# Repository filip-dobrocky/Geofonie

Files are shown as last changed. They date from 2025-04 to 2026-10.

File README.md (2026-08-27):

# Geofonie
A networked sound art installation born out of [Trychtyr](https://svitava.org/project/trychtyr/) project of [SVITAVA transmedia art lab](https://svitava.org/).

This repository contains all of the software and also the hardware documentation.

The ESP32 firmware is in the `PlatformIO` directory, the `Daisy` directory contains Gen patches for [Oopsy](github.com/electro-smith/oopsy/), current: `Granular/geofonie_gen_simpler2.maxpat`.

# Dependencies
- [OSC Control](https://git.iem.at/uC/OSC_control)
- [MIDI Library](https://docs.arduino.cc/libraries/midi-library/)
- [ESP-FlexyStepper](https://docs.arduino.cc/libraries/esp-flexystepper/)
- [ESP32Servo](https://docs.arduino.cc/libraries/esp32servo/)
- [Pololu VL53L4CD](https://github.com/pololu/vl53l4cd-arduino)

# Roto MIDI messages:
    CC1: sensor value
    CC2: servo min angle / (sample pos) loop start pos
    CC3: servo max angle / (sample pos) loop end pos
    CC4: rotation speed  / (sample pos) loop speed
    CC5..12: misc1..8

# OSC messages:
    [obj_id]: 0, 1, 2, 3, 4
    [value] : 0..1

## Roto objects

### Rotation
#### Speed:
`/toRoto/rotation/speed [obj_id] [value]`  
#### Direction:
`/toRoto/rotation/direction [obj_id] [value]`  

### Servo
#### Center position:  
`/toRoto/servo/center [obj_id] [value]`  
#### Angle range (0 = no movement):  
`/toRoto/servo/angle [obj_id] [value]`  
#### Movement mode:
    0 = STATIC
    1 = ALTERNATING
    2 = LINEAR
`/toRoto/servo/mode [obj_id] [value]`  
#### Movement direction (0 / 1):  
`/toRoto/servo/direction [obj_id] [value]`  
#### Servo calibration (0 / 1):
Stop automatic movement and set angle based on `center` message  
`/toRoto/servo/calibrate [obj_id] [value]`  

### Sensor calibration
#### Lower limit:
`/toRoto/calibration/minDist [obj_id] [value]`  
#### Upper limit:
`/toRoto/calibration/maxDist [obj_id] [value]`  
#### Auto-calibration (0 / 1):
Scans the object once: the servo is held still for a full rotation at each angle, then
the distance window (`minDist`/`maxDist`) and the servo tilt band (`center`/`angle`) are
derived from what was measured. Takes about a minute. Runs on every startup, so the values
are never stored -- the object has usually moved by the next power-up anyway.  
`/toRoto/calibration/auto [obj_id] [value]`  
#### Measured calibration:
Sent from object to all devices when a scan finishes  
`/fromRoto/calibration [obj_id] [minDist] [maxDist] [center_angle] [angle_dif]`  

#### Value read from sensor (0..1):
Sent from object to all devices  
`/fromRoto/reading [obj_id] [value]`  

### Misc parameters:
Sent to Daisy Seed as MIDI CC 5-12 to be used as sound synthesis parameters  
`/toRoto/misc/[1-8] [obj_id] [value]`   

## Acid objects

Generic parameters sent to Daisy Seed as MIDI CC 1-10  
`/toAcid/param[1-10] [obj_id] [value]`  

## Global
### Rotation speed
`/toRoto/global/rotation/speed [value]`
### Rotation direction
`/toRoto/global/rotation/direction [value]`
### Roto misc
`/toRoto/global/misc/[1-8] [value]` 
### Sensor calibration
`/toRoto/global/calibration/minDist [value]`, `/toRoto/global/calibration/maxDist [value]`, `/toRoto/global/calibration/auto [value]`
### Acid params
`/toAcid/global/param[1-10] [value]` 

#### Object alive, with firmware version:
`/fromRoto/ping [obj_id] [fw_version]`, `/fromAcid/ping [obj_id] [fw_version]`

# Network config

Network parameters are defined in `NetworkConfig.h`

SSID: `TrychtyrLOM`
Password: `LomLomLom`

Port for sending to mesh objects: `54345`
Port for listening to messages from mesh: `54355`

There is no infrastructure access point. Every object runs painlessMesh in
AP_STA and advertises `TrychtyrLOM` as its own softAP, so **join any object's
AP** and send to its gateway address (`10.x.y.1`). That object relays every
`/to...` message it receives across the mesh, and re-emits telemetry it hears
from the mesh to its own AP, so it does not matter which one you attach to.
Roto and Acid share one mesh; Roto object 0 is the mesh root anchor.

# Firmware

Object ids live in NVS, not in the binary, so one image serves every object.

1. **Provision** each board once over USB with its own env: `xiao_dev_0` ...
   `xiao_dev_4` (in `ESPRoto/` or `ESPAcid/`). This writes the id and nothing
   else depends on it afterwards.
2. **Update** over the mesh: join any object's AP and run
   `python PlatformIO/tools/ota_update.py --project roto --watch`
   (`--project acid` for the Acid objects; the two roles cannot flash each
   other, so run it once per project). It builds `xiao_deploy`, uploads to the
   object's `/fw` endpoint, and that object distributes to the mesh and
   self-flashes last. `http://10.x.y.1/` serves the same thing as a form.

A crash-looping image can only be recovered over USB, so bench one board with
`xiao_ota` before distributing.

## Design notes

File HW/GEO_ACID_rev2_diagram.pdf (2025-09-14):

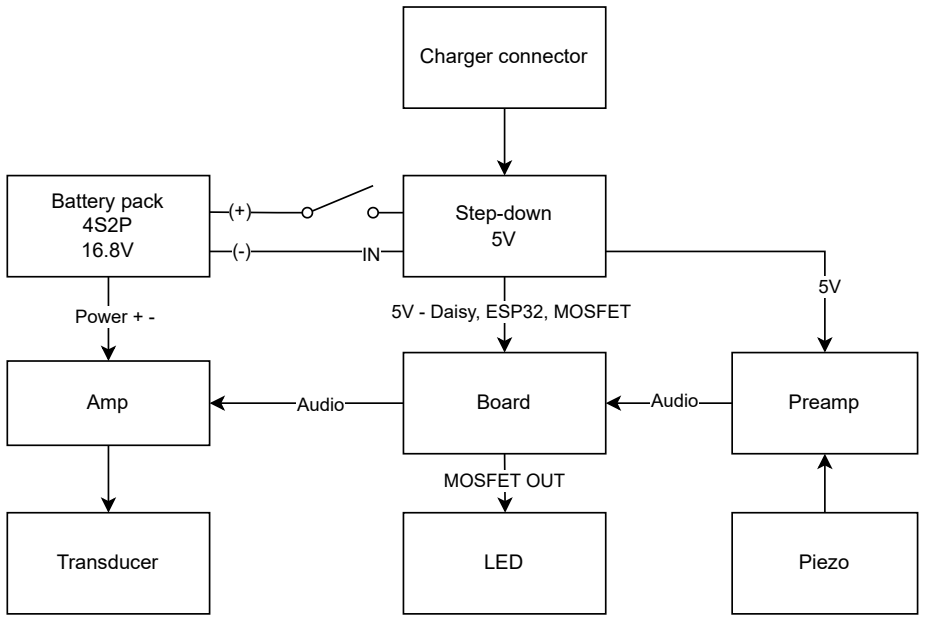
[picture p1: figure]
Power + -; Battery pack 4S2P 16.8V; 5V - Daisy, ESP32, MOSFET; Step-down; Amp; Transducer; Audio; MOSFET OUT; Board; Piezo; Preamp; Charger connector; LED

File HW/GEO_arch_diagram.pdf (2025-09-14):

COMMUNICATION + LOGIC | AUDIO

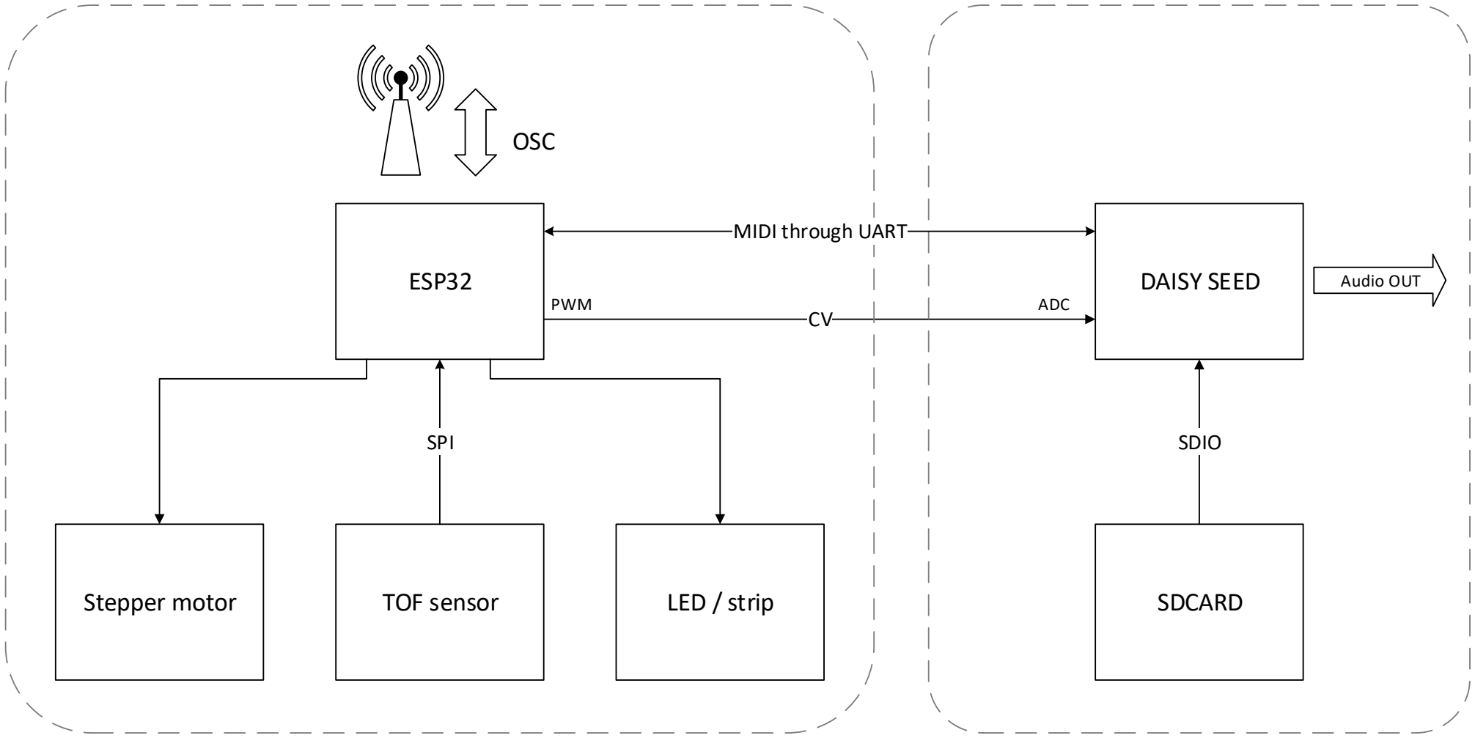
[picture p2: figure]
ESP32; OSC; Stepper motor; TOF sensor; LED / strip; DAISY SEED; SDCARD; SPI; SDIO; Audio OUT; PWM; ADC; MIDI through UART

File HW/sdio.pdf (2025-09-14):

D3 | D2 | D1 | D0 | CMD | CLK
3V | GND | CLK | D0 | CMD | D3 | D1 | D2

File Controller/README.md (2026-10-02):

# geo_controller

A new Flutter project.

## Getting Started

This project is a starting point for a Flutter application.

A few resources to get you started if this is your first Flutter project:

- [Learn Flutter](https://docs.flutter.dev/get-started/learn-flutter)
- [Write your first Flutter app](https://docs.flutter.dev/get-started/codelab)
- [Flutter learning resources](https://docs.flutter.dev/reference/learning-resources)

For help getting started with Flutter development, view the
[online documentation](https://docs.flutter.dev/), which offers tutorials,
samples, guidance on mobile development, and a full API reference.

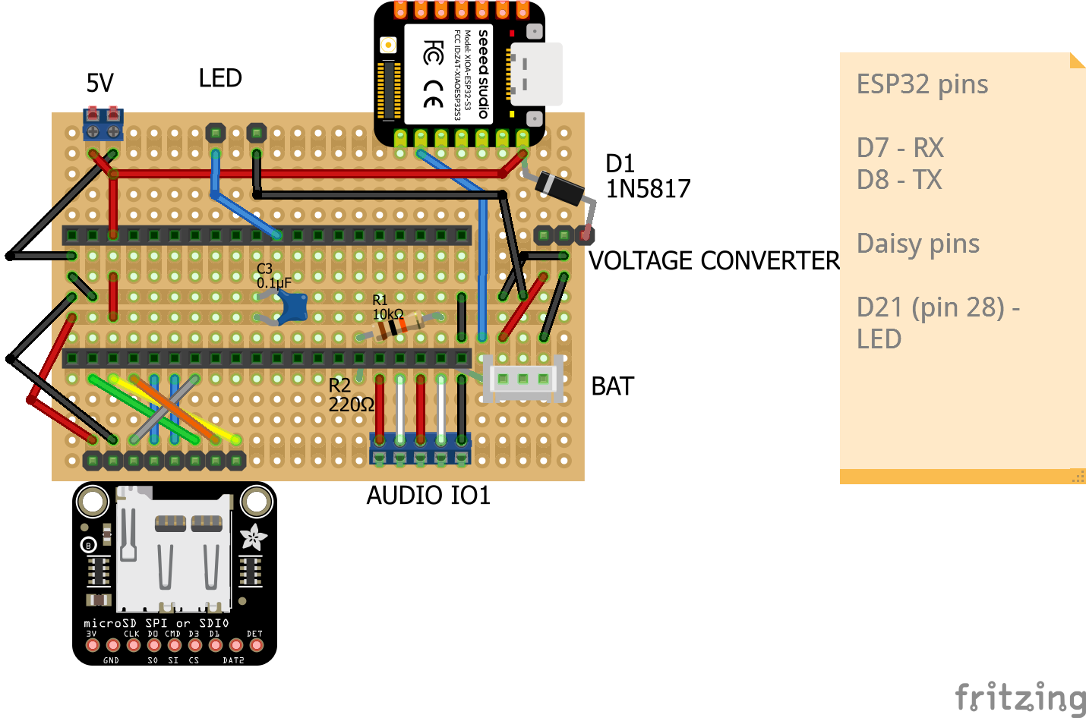
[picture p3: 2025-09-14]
HW/pcb_acid_rev1.png

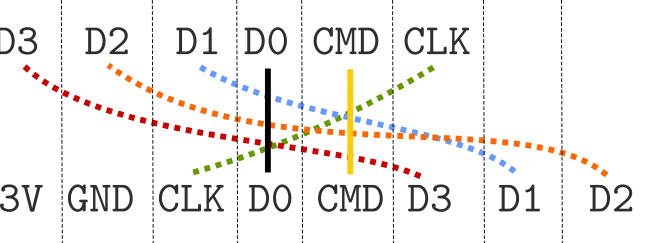
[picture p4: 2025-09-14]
HW/sdio.png

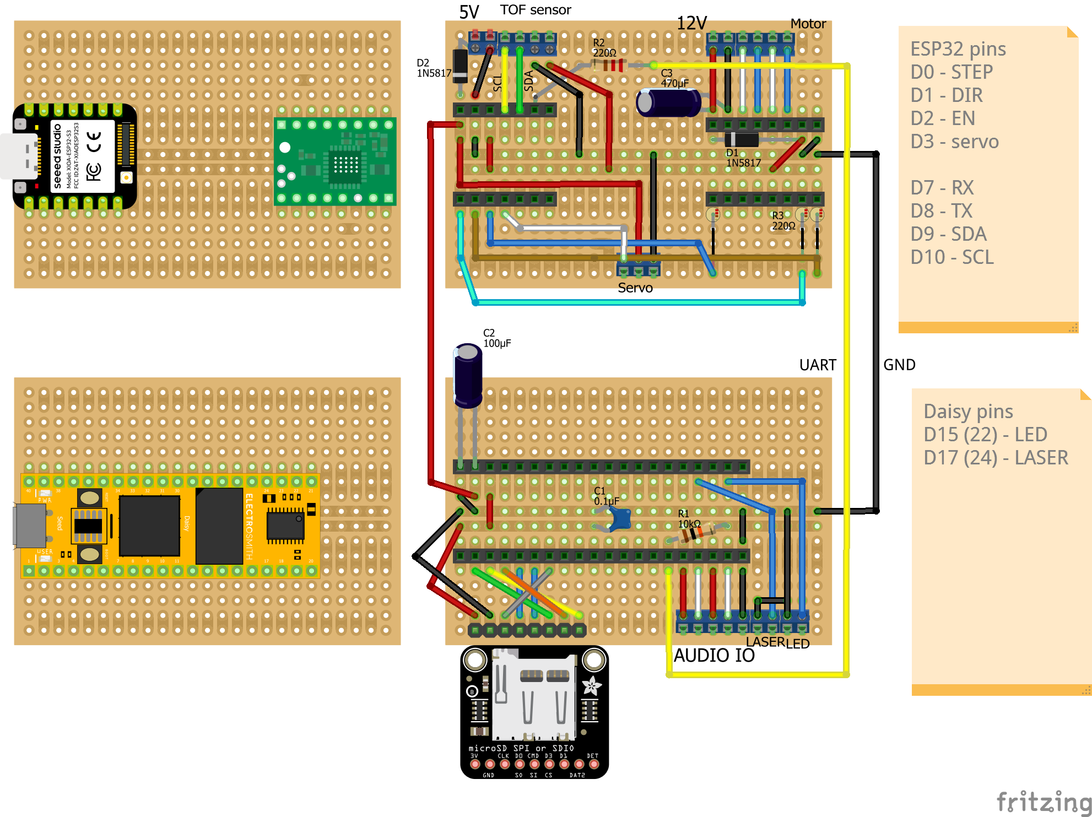
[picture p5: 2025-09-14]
HW/pcb_roto.png

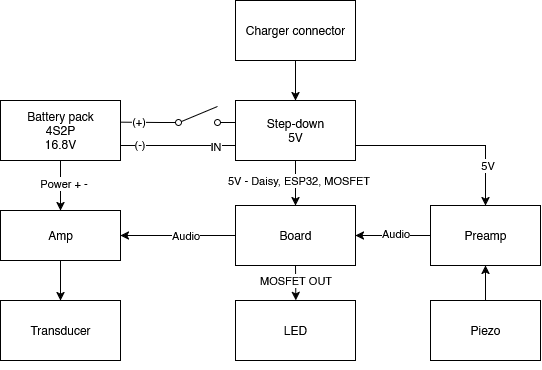
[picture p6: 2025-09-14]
HW/GEO_ACID_rev2_diagram.png

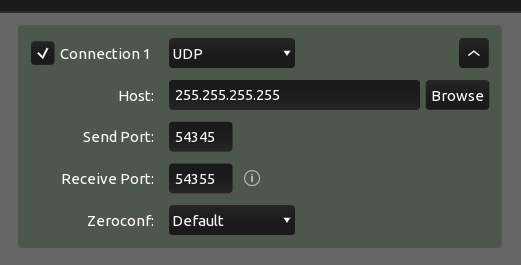
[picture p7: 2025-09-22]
TouchOSC/udp_config.png

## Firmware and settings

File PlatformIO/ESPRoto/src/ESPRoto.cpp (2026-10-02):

/*
 * ESPRoto.cpp
 * Part of Geofonie project
 * Copyright (C) 2024 Filip Dobrocky, Trychtyr collective
 *
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
 * You should have received a copy of the GNU General Public License
 * along with this program.  If not, see <https://www.gnu.org/licenses/>.
 */

#include <Arduino.h>
#include <MIDI.h>
#include <Wire.h>
#include <VL53L4CD.h>
#include <ESP_FlexyStepper.h>
#include <ESP32Servo.h>

// GeoNode.h (painlessMesh) must pull in TaskScheduler: it sets _TASK_STD_FUNCTION
// first, and including TaskScheduler.h ahead of it locks in a Task without
// std::function callbacks, which mesh.addTask() then fails to construct.
#include "GeoNode.h"
#include "GeoIdentity.h"
#include "GeoOta.h"
#include "GEOUtils.h"
#include "Smoothing.h"
#include "Sequencer.h"

// Constants
const char* TAG = "geo_roto";

#define FW_VERSION 2

// Object id at runtime: read from NVS by the generic OTA image, seeded over USB
// by the per-node provisioning envs (-DOBJ_ID=n). -1 means unprovisioned.
int g_obj_id = -1;

#ifndef BAD_DRIVER
#define BAD_DRIVER 0
#endif

#ifdef BOARD_XIAO
#define MS1_PIN D4
#define MS2_PIN D5
#define MS3_PIN D6

#define RX_PIN D7
#define TX_PIN D8

#define I2C_SDA D9
#define I2C_SCL D10

#define STEP_PIN D0
#define DIR_PIN D1
#define EN_PIN D2

#define SERVO_PIN D3
#endif

#define MIN_ANGLE 40
#define MAX_ANGLE 99

#define MIN_DISTANCE 120
#define MAX_DISTANCE 400

#define STEPS_PER_ROTATION 13500
#define DEGREES_PER_ROTATION 10

// ---- Auto-calibration ----
// Runs once per boot. Default: the servo stays at center_angle while the stepper
// turns CAL_TURNS times, and only the distance band is set. -DFULL_CALIBRATION
// instead holds the servo for a full rotation at each angle across the range and
// also derives the servo band (center/angle) from where the object is.
// Upper bound, not a haste setting: a rotation takes STEPS_PER_ROTATION/CAL_SPEED
// seconds and samples every SENSOR_PERIOD, so faster thins the azimuthal scan
// (4000 -> 3.4 s -> ~140 samples/rotation -> one every 2.6 degrees).
#define CAL_SPEED 4000
#ifdef FULL_CALIBRATION
#define CAL_ANGLE_STEP 4
#define CAL_ANGLE_COUNT (((MAX_ANGLE - MIN_ANGLE) / CAL_ANGLE_STEP) + 1)
#define CAL_TURNS 1
#else
#define CAL_ANGLE_COUNT 1
#define CAL_TURNS 2
#endif
// Servo travel between two adjacent stops; also lets the stepper reach speed.
#define CAL_SETTLE_MS 200
// Below this span across a rotation an angle is the pedestal, not the object.
#define CAL_FLAT_SPAN_MM 8
// Widens the measured window on each edge by this share of its span, so the
// extremes don't sit exactly on 0 and 127.
#define CAL_PAD_PCT 10
// Below this share of in-range samples the sensor is pointing past the object.
#define CAL_MIN_VALID_PCT 50

#define MISC_PARAM_NUM 8

// Sensor telemetry period. Every reading is a mesh broadcast, so five objects at
// 500 ms is already ~10 messages/s on a shared bus -- raise before lowering.
#define READING_PERIOD 500

// Sensor integration window (10..200 ms). Longer = quieter, and cheaper than
// averaging it back out in software. Trade against NUM_READINGS in Smoothing.h.
#define SENSOR_TIMING_BUDGET 20
// Poll margin: keep it above the budget so sense() isn't polling I2C for nothing.
#define SENSOR_PERIOD (SENSOR_TIMING_BUDGET + 4)

#ifndef NO_SENSOR
#define NO_SENSOR 0
#endif


// ---- Enums ----
enum TransportMode {
  STATIC,
  LINEAR,
  ALTERNATING
};

// ---- Globals ----
const char *base_address = "/toRoto";
const char *broadcast_address = "/fromRoto";

GeoConfig geo_cfg{-1, false, base_address, broadcast_address, "roto"};
GeoNode node(geo_cfg);
GeoOta ota(node.mesh(), "roto");

// ---- Misc OSC params  ----
constexpr int NUM_MISC = MISC_PARAM_NUM;
constexpr const char* misc_param_names[NUM_MISC] = {
  "/misc/1", "/misc/2", "/misc/3", "/misc/4",
  "/misc/5", "/misc/6", "/misc/7", "/misc/8"
};
constexpr const char* misc_param_names_global[NUM_MISC] = {
  "/global/misc/1", "/global/misc/2", "/global/misc/3", "/global/misc/4",
  "/global/misc/5", "/global/misc/6", "/global/misc/7", "/global/misc/8"
};
OSC_receive_msg rcv_misc[NUM_MISC] = {
  OSC_receive_msg(misc_param_names[0]),
  OSC_receive_msg(misc_param_names[1]),
  OSC_receive_msg(misc_param_names[2]),
  OSC_receive_msg(misc_param_names[3]),
  OSC_receive_msg(misc_param_names[4]),
  OSC_receive_msg(misc_param_names[5]),
  OSC_receive_msg(misc_param_names[6]),
  OSC_receive_msg(misc_param_names[7])
};

OSC_receive_msg rcv_misc_global[NUM_MISC] = {
  OSC_receive_msg(misc_param_names_global[0]),
  OSC_receive_msg(misc_param_names_global[1]),
  OSC_receive_msg(misc_param_names_global[2]),
  OSC_receive_msg(misc_param_names_global[3]),
  OSC_receive_msg(misc_param_names_global[4]),
  OSC_receive_msg(misc_param_names_global[5]),
  OSC_receive_msg(misc_param_names_global[6]),
  OSC_receive_msg(misc_param_names_global[7])
};

// Defaults match the gen~ param defaults; the 1 s refresh would otherwise
// overwrite them with zeros before anything sends a value.
float misc_osc[NUM_MISC] = {1.0f, 0.0f, 0.0f, 0.0f, 0.0f, 0.0f, 0.1875f, 0.1f};

// ---- Named OSC params ----
OSC_receive_msg rcv_rotation_speed("/rotation/speed");
OSC_receive_msg rcv_rotation_direction("/rotation/direction");
OSC_receive_msg rcv_global_rotation_speed("/global/rotation/speed");
OSC_receive_msg rcv_global_rotation_direction("/global/rotation/direction");

OSC_receive_msg rcv_servo_center("/servo/center");
OSC_receive_msg rcv_servo_angle("/servo/angle");
OSC_receive_msg rcv_servo_mode("/servo/mode");
OSC_receive_msg rcv_servo_direction("/servo/direction");
OSC_receive_msg rcv_servo_calibrate("/servo/calibrate");

OSC_receive_msg rcv_min_distance("/calibration/minDist");
OSC_receive_msg rcv_max_distance("/calibration/maxDist");
OSC_receive_msg rcv_calibration_auto("/calibration/auto");
OSC_receive_msg rcv_global_min_distance("/global/calibration/minDist");
OSC_receive_msg rcv_global_max_distance("/global/calibration/maxDist");
OSC_receive_msg rcv_global_calibration_auto("/global/calibration/auto");

OSC_receive_msg rcv_global_auto("/global/auto");

OSC_send_msg snd_ping("/ping");
OSC_send_msg snd_reading("/reading");
OSC_send_msg snd_calibration("/calibration");

// ---- MIDI ----
HardwareSerial MidiSerial(1);

MIDI_CREATE_INSTANCE(HardwareSerial, MidiSerial, midi1);

// ---- Sensor ----
VL53L4CD sensor;
Smoothing sensor_filter;

int sensor_value = 0;
float sensor_value_osc;


float min_distance_osc = 0;
float max_distance_osc = 1;

// ---- Auto-calibration state ----
enum CalPhase {
  CAL_OFF,
  CAL_SETTLE,   // servo moving to the next angle, nothing recorded
  CAL_MEASURE   // servo still, recording one full rotation
};

struct CalRow {
  uint16_t min_mm;
  uint16_t max_mm;
  uint16_t valid;
  uint16_t total;
};

CalPhase cal_phase = CAL_OFF;
CalRow cal_rows[CAL_ANGLE_COUNT];
uint8_t cal_index = 0;
int32_t cal_start_steps = 0;
uint32_t cal_settle_until = 0;
uint32_t cal_deadline = 0;

// Transport state the scan takes over, restored when it ends. Messages arriving
// mid-run are parked here instead of applied.
int cal_saved_speed = 0;
int cal_saved_direction = 1;
enum TransportMode cal_saved_mode = STATIC;

// ---- Speed settings ----
const int SPEED_MIN = 2;
const int SPEED_MAX = 4000; // max freq 0.22 Hz
const int ACCELERATION = 1000;
const int DECELERATION = 1000;

int stepper_speed = SPEED_MIN;

// ---- Transport params----
int angle_dif = ((MAX_ANGLE - MIN_ANGLE) / 2);
int center_angle = MIN_ANGLE + angle_dif;
int angle = center_angle;
int servo_direction = 1;
enum TransportMode transport_mode = STATIC;
float loop_length = 0.1;
bool calibrating = false;

// ---- Midi controls ----
uint8_t start_pos_midi = 0;
uint8_t end_pos_midi = 0;
uint8_t loop_pos = 0;
uint8_t speed_midi = 0;
uint8_t sensor_midi = 0;
uint8_t misc_midi[MISC_PARAM_NUM] = {127};


ESP_FlexyStepper stepper;
int rotation_direction = 1;

Servo servo;

// ---- TaskScheduler ----
Scheduler runner;

// Forward declaration for the stepper disable task callback
void disable_stepper_driver();

Task t_disable_stepper(1000UL, TASK_ONCE, &disable_stepper_driver, &runner, false);

// For direction change: schedule stepper_start after 2s instead of blocking delay
void start_stepper_after_direction_change();
Task t_start_stepper_dir(2000UL, TASK_ONCE, &start_stepper_after_direction_change, &runner, false);
int pending_rotation_direction = 1;


// ---- Sequencer ----
// Object 0 plays the score; started at runtime, once the id is known.
Sequencer sequencer(node);

// ---- Function declarations ----

void stepper_start(int dir);
void stepper_stop();
void servo_tilt(int angle);
void transport();
void midi_send();
void ping();
void send_info();
void sense();

void start_calibration();
void update_calibration(uint16_t raw_mm, bool raw_valid);
void finish_calibration(bool completed);

void servo_osc_callback(OSCMessage& m);
void rotation_osc_callback(OSCMessage& m);
void misc_osc_callback(OSCMessage& m);
void calibration_osc_callback(OSCMessage& m);
void auto_osc_callback(OSCMessage& m);


// ---- Function definitions ----

void setup() {
  pinMode(LED_BUILTIN, OUTPUT);
  pinMode(STEP_PIN, OUTPUT);
  pinMode(DIR_PIN, OUTPUT);
  pinMode(EN_PIN, OUTPUT);


  MidiSerial.setPins(RX_PIN, TX_PIN);
  midi1.begin(MIDI_CHANNEL_OMNI);
  
  Serial.begin(115200);
  delay(1000);

  // Sensor init
  Wire.begin(I2C_SDA, I2C_SCL);
  Wire.setClock(400000); // use 400 kHz I2C

  sensor.setTimeout(500);
  if (!sensor.init())
  {
    ESP_LOGE(TAG, "Failed to detect and initialize sensor!");
  #if NO_SENSOR == 0
    while (1) {
      digitalWrite(LED_BUILTIN, HIGH);
      delay(250);
      digitalWrite(LED_BUILTIN, LOW);
      delay(250);
    }
  #endif
  }

  sensor.setRangeTiming(SENSOR_TIMING_BUDGET, 0);
  sensor.startContinuous();

  // Motors init
  servo.attach(SERVO_PIN);

#if BAD_DRIVER
  // legacy for A4988
  pinMode(MS1_PIN, OUTPUT);
  pinMode(MS2_PIN, OUTPUT);
  pinMode(MS3_PIN, OUTPUT); 
  digitalWrite(MS1_PIN, HIGH);
  digitalWrite(MS2_PIN, HIGH);
  digitalWrite(MS3_PIN, HIGH);
#endif

  runner.startNow();

  stepper.connectToPins(STEP_PIN, DIR_PIN);
  stepper.setSpeedInStepsPerSecond(SPEED_MIN);
  stepper.setAccelerationInStepsPerSecondPerSecond(ACCELERATION);
  stepper.setDecelerationInStepsPerSecondPerSecond(DECELERATION);
  stepper.startAsService(1);
  stepper_start(rotation_direction);

#ifdef OBJ_ID
  // Provisioning build (per-node env): seed the id into NVS over USB.
  g_obj_id = OBJ_ID;
  GeoIdentity::save(OBJ_ID);
  // A USB flash bypasses the OTA bookkeeping; drop the stale installed-md5
  // record so the next mesh OTA offer is not wrongly deduped.
  if (LittleFS.begin(true)) LittleFS.remove("/ota_fw.json");
#else
  // Generic OTA image: identity comes from NVS only.
  g_obj_id = GeoIdentity::load(-1);
#endif
  ESP_LOGI(TAG, "Roto starting up, obj id %d, fw v%d", g_obj_id, FW_VERSION);

  node.setIdentity(g_obj_id, g_obj_id == 0);
  node.begin(NetworkConfig::ssid, NetworkConfig::password);
  ota.begin();

  // Setup OSC receive handlers for misc params
  for (int i = 0; i < NUM_MISC; ++i) {
    rcv_misc[i].init(misc_osc_callback);
    rcv_misc_global[i].init(misc_osc_callback);
  }

  rcv_rotation_speed.init(rotation_osc_callback);
  rcv_rotation_direction.init(rotation_osc_callback);
  rcv_global_rotation_speed.init(rotation_osc_callback);
  rcv_global_rotation_direction.init(rotation_osc_callback);
  rcv_servo_center.init(servo_osc_callback);
  rcv_servo_angle.init(servo_osc_callback);
  rcv_servo_mode.init(servo_osc_callback);
  rcv_servo_direction.init(servo_osc_callback);
  rcv_servo_calibrate.init(servo_osc_callback);
  rcv_min_distance.init(calibration_osc_callback);
  rcv_max_distance.init(calibration_osc_callback);
  rcv_calibration_auto.init(calibration_osc_callback);
  rcv_global_min_distance.init(calibration_osc_callback);
  rcv_global_max_distance.init(calibration_osc_callback);
  rcv_global_calibration_auto.init(calibration_osc_callback);
  rcv_global_auto.init(auto_osc_callback);

  snd_ping.init(broadcast_address);
  snd_reading.init(broadcast_address);
  snd_calibration.init(broadcast_address);

  if (g_obj_id == 0) sequencer.start();

  start_calibration();
}

void loop() {
  runner.execute();
  node.update();
  ota.update();
  sequencer.update();

  sense();
  transport();
  midi_send();
  ping();
  send_info();

  // Unprovisioned board (generic image, empty NVS): fast blink. It still joins
  // the mesh and still takes OTA, it just ignores every id-addressed message.
  if (g_obj_id < 0) {
    static uint32_t blink = 0;
    if (millis() - blink >= 150) {
      digitalWrite(LED_BUILTIN, !digitalRead(LED_BUILTIN));
      blink = millis();
    }
  }

#if CORE_DEBUG_LEVEL > 0
  static uint32_t print_elapsed = millis();
  if (millis() - print_elapsed >= 1000) {
    Serial.printf("Sensor: %d, Servo angle: %d, Stepper speed: %d\n", sensor_value, angle, stepper_speed);
    // ESP_LOGD(TAG, "Free Heap: %d, Stack: %d", ESP.getFreeHeap(), uxTaskGetStackHighWaterMark(NULL));
    print_elapsed = millis();
  }
#endif

  // loop() shares core 0 with the idle task the WDT watches; without a yield it
  // never runs and the panic fires after 5 s.
  delay(1);
}

// ---- Function definitions ----

void sense() {
  static uint32_t last_time = 0;
  if (millis() - last_time < SENSOR_PERIOD) return;

#if NO_SENSOR == 0
  // Never call the blocking read(): it spins on dataReady() for the whole 500 ms
  // io_timeout, and loop() stalling that long stops MIDI, the mesh and the servo.
  if (!sensor.dataReady()) return;
  last_time = millis();

  sensor.read(false);
  uint16_t raw_mm = sensor.ranging_data.range_mm;
  bool raw_valid = sensor.ranging_data.range_status == 0;
  sensor_value = sensor_filter.filter(raw_mm);
#else
  last_time = millis();
  sensor_value = (MIN_DISTANCE + MAX_DISTANCE) / 2;
  uint16_t raw_mm = sensor_value;
  bool raw_valid = true;
#endif
  update_calibration(raw_mm, raw_valid);

  sensor_value_osc = constrain((float)(sensor_value - MIN_DISTANCE) / (MAX_DISTANCE - MIN_DISTANCE), 0.0f, 1.0f);
  int min_d = (int)floor(MIN_DISTANCE + min_distance_osc * (MAX_DISTANCE - MIN_DISTANCE));
  int max_d = (int)floor(MIN_DISTANCE + max_distance_osc * (MAX_DISTANCE - MIN_DISTANCE));
  if (max_d <= min_d)
    min_d--;
  sensor_midi = SCALE_TO_MIDI(sensor_value, min_d, max_d);

  // Update misc_midi from misc_osc
  for (int i = 0; i < NUM_MISC; ++i) {
    misc_midi[i] = FLOAT_TO_MIDI(misc_osc[i]);
  }
}

// === Auto-calibration ===

#ifdef FULL_CALIBRATION
static inline int cal_angle(uint8_t i) { return MIN_ANGLE + i * CAL_ANGLE_STEP; }
#else
static inline int cal_angle(uint8_t) { return center_angle; }
#endif

void start_calibration() {
  if (cal_phase != CAL_OFF) return;

  cal_saved_speed = stepper_speed;
  cal_saved_direction = rotation_direction;
  cal_saved_mode = transport_mode;

  // STATIC is what keeps transport() off the servo while the scan holds each angle
  transport_mode = STATIC;
  stepper_speed = CAL_SPEED;
  stepper.setSpeedInStepsPerSecond(CAL_SPEED);
  t_disable_stepper.disable();
  stepper_start(rotation_direction);

  for (int i = 0; i < CAL_ANGLE_COUNT; ++i) cal_rows[i] = {UINT16_MAX, 0, 0, 0};

  cal_index = 0;
  angle = cal_angle(0);
  servo.write(angle);
  cal_settle_until = millis() + CAL_SETTLE_MS;
  cal_phase = CAL_SETTLE;
  cal_deadline = millis() + 2UL * CAL_ANGLE_COUNT *
                 ((1000UL * CAL_TURNS * STEPS_PER_ROTATION) / CAL_SPEED + CAL_SETTLE_MS);

  ESP_LOGI(TAG, "Calibration started, %d angles from %d to %d deg",
           CAL_ANGLE_COUNT, cal_angle(0), cal_angle(CAL_ANGLE_COUNT - 1));
}

void update_calibration(uint16_t raw_mm, bool raw_valid) {
  if (cal_phase == CAL_OFF) return;

  if ((int32_t)(millis() - cal_deadline) >= 0) {
    ESP_LOGW(TAG, "Calibration timed out at angle %d", cal_angle(cal_index));
    finish_calibration(false);
    return;
  }

  // The moving average still carries samples from the previous angle until it has
  // refilled, so a reading only counts once the whole window is in range.
  static uint8_t valid_streak = 0;
  const bool in_range = raw_valid && raw_mm >= MIN_DISTANCE && raw_mm <= MAX_DISTANCE;
  if (in_range) {
    if (valid_streak < NUM_READINGS) valid_streak++;
  } else {
    valid_streak = 0;
  }

  if (cal_phase == CAL_SETTLE) {
    if (millis() < cal_settle_until) return;
    // Latched after settling, so the recorded window is a full 360 degrees
    cal_start_steps = stepper.getCurrentPositionInSteps();
    cal_phase = CAL_MEASURE;
    return;
  }

  CalRow &row = cal_rows[cal_index];
  row.total++;
  if (in_range && valid_streak >= NUM_READINGS) {
    row.valid++;
    if (sensor_value < row.min_mm) row.min_mm = sensor_value;
    if (sensor_value > row.max_mm) row.max_mm = sensor_value;
  }

  // Read once: abs() is a macro and would poll the stepper service twice
  const int32_t turned = stepper.getCurrentPositionInSteps() - cal_start_steps;
  if (abs(turned) < CAL_TURNS * STEPS_PER_ROTATION) return;

  ESP_LOGD(TAG, "Calibration angle %d: %d..%d mm, %d/%d valid",
           cal_angle(cal_index), row.min_mm, row.max_mm, row.valid, row.total);

  if (++cal_index >= CAL_ANGLE_COUNT) {
    finish_calibration(true);
    return;
  }

  angle = cal_angle(cal_index);
  servo.write(angle);
  valid_streak = 0;
  cal_settle_until = millis() + CAL_SETTLE_MS;
  cal_phase = CAL_SETTLE;
}

void finish_calibration(bool completed) {
  int run_start = -1, run_len = 0, best_start = -1, best_len = 0;

  // ponytail: flatness alone can't tell a rotationally symmetric object (cylinder,
  // vase) from the pedestal -- both read constant, and the band collapses to the
  // defaults. Upgrade path is ranging_data.signal_rate_kcps, which the driver
  // already fills in: sky returns no signal whatever the object's shape.
  for (int i = 0; completed && i < CAL_ANGLE_COUNT; ++i) {
    const CalRow &r = cal_rows[i];
    bool object = r.total > 0 && r.valid * 100 >= r.total * CAL_MIN_VALID_PCT;   // else sky
#ifdef FULL_CALIBRATION
    object = object && (r.max_mm - r.min_mm) >= CAL_FLAT_SPAN_MM;               // else pedestal
#endif
    if (!object) {
      run_start = -1;
      continue;
    }
    if (run_start < 0) { run_start = i; run_len = 0; }
    if (++run_len > best_len) { best_len = run_len; best_start = run_start; }
  }

  if (best_len > 0) {
    uint16_t min_mm = UINT16_MAX, max_mm = 0;
    for (int i = best_start; i < best_start + best_len; ++i) {
      if (cal_rows[i].min_mm < min_mm) min_mm = cal_rows[i].min_mm;
      if (cal_rows[i].max_mm > max_mm) max_mm = cal_rows[i].max_mm;
    }
    const int pad = (max_mm - min_mm) * CAL_PAD_PCT / 100;
    const int lo_mm = constrain((int)min_mm - pad, MIN_DISTANCE, MAX_DISTANCE - 1);
    const int hi_mm = constrain((int)max_mm + pad, lo_mm + 1, MAX_DISTANCE);
    min_distance_osc = (float)(lo_mm - MIN_DISTANCE) / (MAX_DISTANCE - MIN_DISTANCE);
    max_distance_osc = (float)(hi_mm - MIN_DISTANCE) / (MAX_DISTANCE - MIN_DISTANCE);

#ifdef FULL_CALIBRATION
    const int lo_ang = cal_angle(best_start);
    const int hi_ang = cal_angle(best_start + best_len - 1);
    center_angle = (lo_ang + hi_ang) / 2;
    angle_dif = (hi_ang - lo_ang) / 2;
#endif

    ESP_LOGI(TAG, "Calibration done: %d..%d mm, angles %d..%d",
             lo_mm, hi_mm, center_angle - angle_dif, center_angle + angle_dif);
  } else {
    ESP_LOGW(TAG, "Calibration found no object band, keeping previous values");
  }

  cal_phase = CAL_OFF;
  transport_mode = cal_saved_mode;
  angle = center_angle;
  servo.write(center_angle);

  stepper_speed = cal_saved_speed;
  stepper.setSpeedInStepsPerSecond(stepper_speed > 0 ? stepper_speed : 1);
  if (stepper_speed == 0) {
    stepper_stop();
  } else if (cal_saved_direction != rotation_direction) {
    rotation_direction = cal_saved_direction;
    stepper_stop();
    pending_rotation_direction = rotation_direction;
    t_start_stepper_dir.restartDelayed(2000UL);
  } else {
    stepper_start(rotation_direction);
  }

  snd_calibration.m.add((float)g_obj_id);
  snd_calibration.m.add(min_distance_osc);
  snd_calibration.m.add(max_distance_osc);
  snd_calibration.m.add((float)center_angle);
  snd_calibration.m.add((float)angle_dif);
  node.send_info(snd_calibration.m);
}

void stepper_start(int dir) {
  t_disable_stepper.disable(); // a stop <1 s ago would otherwise cut the driver mid-run
  digitalWrite(EN_PIN, LOW);
  stepper.startJogging(dir);
  ESP_LOGD(TAG, "Stepper started with speed %d", stepper_speed);
}

void disable_stepper_driver() {
    digitalWrite(EN_PIN, HIGH);
    ESP_LOGD(TAG, "Stepper disabled (TaskScheduler)");
}

void stepper_stop() {
    stepper.stopJogging();
    t_disable_stepper.restartDelayed(1000UL);
    ESP_LOGD(TAG, "Stepper stop requested (non-blocking)");
}


void start_stepper_after_direction_change() {
    if (stepper_speed == 0) return; // speed went to 0 during the pause
    stepper_start(pending_rotation_direction);
    ESP_LOGD(TAG, "Stepper started after direction change (TaskScheduler)");
}
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

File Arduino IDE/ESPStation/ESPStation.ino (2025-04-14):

#include <ArduinoOSCWiFi.h>
#include <MIDI.h>
#include <Wire.h>
#include <VL53L4CD.h>
#include <ESP_FlexyStepper.h>
#include <ESP32Servo.h>

#include "../NetworkConfig.h"
#include "Smoothing.h"

// Constants

#define OBJ_ID 1
#define BAD_DRIVER 0

#define MS1_PIN D4
#define MS2_PIN D5
#define MS3_PIN D6

#define RX_PIN D7
#define TX_PIN D8

#define I2C_SDA D9
#define I2C_SCL D10

#define STEP_PIN D0
#define DIR_PIN D1
#define EN_PIN D2

#define SERVO_PIN D3

#define MIN_ANGLE 40
#define MAX_ANGLE 99

#define MIN_DISTANCE 200
#define MAX_DISTANCE 400

#define STEPS_PER_ROTATION 13500
#define DEGREES_PER_ROTATION 10

#define MISC_PARAM_NUM 6

// Macros

#define SCALE_TO_MIDI(val, min, max) map(constrain((val), (min), (max)), (min), (max), 0, 127)
#define FLOAT_TO_MIDI(val) (int)constrain(floor((val) * 127.0), 0, 127)

// Enums

enum TransportMode {
  STATIC,
  LINEAR,
  ALTERNATING
};

// Globals

bool connected = false;

HardwareSerial MidiSerial(1);

MIDI_CREATE_INSTANCE(HardwareSerial, MidiSerial, midi1);

VL53L4CD sensor;

Smoothing sensor_filter;

const IPAddress ip(GET_ROTO_IP(OBJ_ID));
const IPAddress gateway(NetworkConfig::gateway);
const IPAddress subnet(NetworkConfig::subnet);

int sensor_value = 0;
float sensor_value_osc;

float min_distance_osc = 0;
float max_distance_osc = 1;

// Speed settings
const int SPEED_MIN = 2;
const int SPEED_MAX = 8000; // can be tuned
const int ACCELERATION = 1000;
const int DECELERATION = 2000;

int stepper_speed = SPEED_MIN;

// Transport params
int angle_dif = ((MAX_ANGLE - MIN_ANGLE) / 2);
int center_angle = MIN_ANGLE + angle_dif;
int angle = center_angle;
int servo_direction = 1;
enum TransportMode transport_mode = STATIC;
float loop_length = 0.1;
bool calibration = false;

// Midi controls
uint8_t start_pos_midi = 0;
uint8_t end_pos_midi = 0;
uint8_t loop_pos = 0;
uint8_t speed_midi = 0;
uint8_t sensor_midi = 0;
uint8_t misc_midi[MISC_PARAM_NUM] = {127};

ESP_FlexyStepper stepper;
int rotation_direction = 1;

Servo servo;

//Functions

int normalize_distance(int distance, int radius, int angle) {
  int difference = radius - radius / cos(DEG_TO_RAD * angle);
  return distance - difference;
}

void wifi_init() {
  // WiFi init
  WiFi.disconnect(true, true);
  delay(1000);
  WiFi.mode(WIFI_STA);

  WiFi.begin(NetworkConfig::ssid, NetworkConfig::password);
  WiFi.config(ip, gateway, subnet);

  uint8_t timeout = 0;
  while (WiFi.status() != WL_CONNECTED && timeout < 10) {

    Serial.print(".");
    delay(500);
    static int count = 0;
    if (count++ > 20) {
      Serial.println("WiFi connection timeout, retry");
      WiFi.begin(NetworkConfig::ssid, NetworkConfig::password);
      count = 0;
    }
    timeout++;
  }
  
  if (timeout < 10) {
    Serial.print("WiFi connected, IP = ");
    Serial.println(WiFi.localIP());
    digitalWrite(LED_BUILTIN, LOW);
    connected = true;
  } else {
    Serial.print("WiFi connection failed");
    digitalWrite(LED_BUILTIN, HIGH);
    connected = false;
  }
}

void stepper_start(int dir) {
  digitalWrite(EN_PIN, LOW);
  stepper.startJogging(dir);
}

void stepper_stop() {
  stepper.stopJogging();
  delay(1000);
  digitalWrite(EN_PIN, HIGH);
  Serial.println("stop");
}
 
void servo_tilt(int angle) {

  servo.write(angle);
}

void transport() {
  // calculate servo speed based on stepper speed
  uint16_t servo_period = (1000 * STEPS_PER_ROTATION) / ((stepper_speed > 0 ? stepper_speed : 1) * DEGREES_PER_ROTATION);
  const uint16_t min_angle = center_angle - angle_dif;
  const uint16_t max_angle = center_angle + angle_dif;

  // servo control
  static uint32_t servo_elapsed = millis();
  if (millis() - servo_elapsed >= servo_period && !calibration && transport_mode != STATIC) {
    Serial.println("Servo period");
    servo_tilt(angle);
    angle += servo_direction;

    if (transport_mode == LINEAR) {
      if (servo_direction > 0 && angle >= max_angle) {
        angle = min_angle;
      } else if (servo_direction < 0 && angle <= min_angle) {
        angle = max_angle;
      }
    } else if (transport_mode == ALTERNATING) {
      if (abs(center_angle - angle) >= angle_dif) {
        servo_direction = -servo_direction;
      }
    }

    servo_elapsed = millis();
  }

  start_pos_midi = SCALE_TO_MIDI(angle, min_angle, max_angle);
  end_pos_midi = (start_pos_midi + FLOAT_TO_MIDI(loop_length)) % 128;
}


void servo_osc(const OscMessage& m) {
  String adr = m.address();

  if (adr.endsWith("/center")) {
    center_angle = MIN_ANGLE + int(floor(m.arg<float>(0) * (MAX_ANGLE - MIN_ANGLE)));
    servo_tilt(center_angle);
  } 
  else if (adr.endsWith("/angle")) {
    int a = int(m.arg<float>(0) * ((MAX_ANGLE - MIN_ANGLE) / 2));
    
    if (center_angle + a > MAX_ANGLE) a = MAX_ANGLE - center_angle;
    else if (center_angle - a < 0)    a = center_angle - MIN_ANGLE;
    angle_dif = a;
  } 
  else if (adr.endsWith("/mode")) {
    switch ((int)m.arg<float>(0)) {
      case 0:
        transport_mode = STATIC;
        break;
      case 1:
        transport_mode = LINEAR;
        break;
      case 2:
        transport_mode = ALTERNATING;
        break;
    }
  } 
  else if (adr.endsWith("/direction")) {
    servo_direction = m.arg<float>(0) > 0 ? -1 : 1;
  } 
  else if (adr.endsWith("/calibrate")) {
    calibration = m.arg<float>(0) > 0;
  }
}

void rotation_osc(const OscMessage& m) {
  String adr = m.address();
  static int last_speed = 1;

  if (adr.endsWith("/speed")) {
    stepper_speed = (int)(floor(m.arg<float>(0) * SPEED_MAX));
    stepper.setSpeedInStepsPerSecond(stepper_speed);
    
    if (stepper_speed == 0 && last_speed > 0) {
      stepper_stop();
    } else if (stepper_speed > 0 && last_speed == 0 ) {
      stepper_start(rotation_direction);
    }
    last_speed = stepper_speed;

    speed_midi = FLOAT_TO_MIDI((float)(stepper_speed) / (SPEED_MAX));
  }
  else if (adr.endsWith("/direction")) {
    rotation_direction = m.arg<float>(0) > 0 ? -1 : 1;
    stepper_stop();
    delay(1000);
    stepper_start(rotation_direction);
  }
}

void misc_osc_callback(const OscMessage& m) {
  String adr = m.address();
  int index = adr.substring(adr.lastIndexOf('/') + 1).toInt();

  if (index >= 1 && index <= MISC_PARAM_NUM) {
    float val = m.arg<float>(0);
    misc_midi[index-1] = FLOAT_TO_MIDI(val);
  }
}
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

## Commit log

2025-03-30 STATIC servo mode, params tweaks...
2025-09-13 rename old Arduino directory
2025-09-13 Added HW documentation to repo
    [objekt1.kicad_pcb, objekt1.kicad_sch, pcb_acid.fzz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]
2025-09-14 STATION_ONLY to prevent mesh splitting
    [ESPAcid.cpp, ESPRoto.cpp]
2025-09-14 remove Arduino IDE directory to avoid confusion
    old version has its tag
    [AccessPoint.ino, ESPStation.ino, ESPStationAcid.ino]
2025-09-22 read sensor distance
2025-09-22 score for esc
2025-09-22 stop button in touchOSC
2026-08-17 sensor + midi timing
2026-08-27 reworked gen roto patch, new misc params
    [ESPRoto.cpp]
2026-08-27 median filter
2026-08-30 core 1 for stepper only
2026-08-30 fixed sensor read + midi, hopefully
    [ESPRoto.cpp]
2026-09-24 simple boot calibration, full sweep behind FULL_CALIBRATION
    Boot calibration now holds the servo at center for two turns and sets
    only the distance band, padded 10% of its span on each edge. The
    per-angle sweep is kept behind -DFULL_CALIBRATION.

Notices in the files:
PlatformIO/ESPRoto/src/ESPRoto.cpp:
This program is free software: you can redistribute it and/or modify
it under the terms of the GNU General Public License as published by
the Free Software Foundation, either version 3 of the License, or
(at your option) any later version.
